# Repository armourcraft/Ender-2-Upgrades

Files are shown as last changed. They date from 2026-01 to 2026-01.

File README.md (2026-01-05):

# Ender 2 Base Upgrade

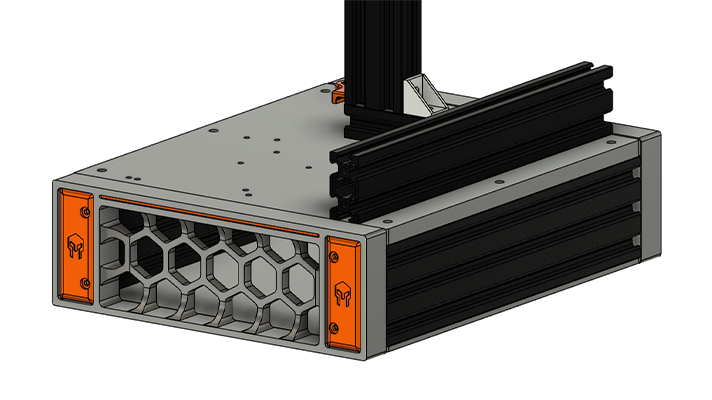
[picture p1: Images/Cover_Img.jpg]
Ender 2 Base Upgrade


This repository is for my upgrades to the original Ender 2. This upgrade can use the existing main board or the BigTreeTech SKR Mini E3 v3 running either Marlin or Klipper. 

## Features
- Footprint is slightly larger making it a little more stable.
- The power supply is under the printer and fully enclosed.
- The new base plate is designed for both old and new main boards.

## Build Tips
Print Settings are as follows:
- FDM Material: ABS recommended, but PETG will work too 
- Layer Height: 0.2mm
- Extrusion Width: 0.4mm
- Infill Percentage: 40% or more recommended
- Infill Type: Gyroid or Grid (others might work as well, experiment)
- Wall Count: 4
- Solid Top/Bottom Layers: 5
- Supports: All files designed to not require supports.

## BOM
### Fasteners:
| Fastener | Qty | Where Used |
| :--- | :---: | :--- |
| M3x6 BHCS  | 12 | grill covers, psu mounts, psu riser |
| M3x8 BHCS | 5 | grill fan, psu fan extension |
| M3x8 FHCS | 2 | power outlet |
| M3x10 BHCS | 3 | main board cover posts |
| M3x12 BHCS | 2 | main board fan mount |
| M3x14 BHCS | 2 | power cable guard |
| M3x16 BHCS | 4 | main board |
| M3 Hex Nuts | 4 | main board fan mount, power cable guard |
| M3 T-Nuts | 3 | power supply |
| M3x5x4 Threaded Inserts | 14 | grills, grill fan, power outlet |
| | | |
| M4x12 BHCS | 4 | bottom panel feet |
| M4 T-Nuts | 4 | bottom panel feet |
| | | |
| M5x10 SHCS | 2 | psu mounts |
| M5x14 BHCS | 6 | base plate extrusions |
| M5x16 SHCS | 12 | grills |
| M5 T-Nuts | 8 | base plate extrusions |

### Parts:
| Item | Qty | Description | Source |
| :---- | :---: | :--- | :--- |
| V-Slot 2060 Extrusion 250mm | 2 | need +1mm for clearance | [Amazon](https://www.amazon.com/dp/B0D1KCGV5D) - came 251mm |
| ABS Sheet 12"x12"x3/8" | 1 | route out new base plate | [Amazon](https://www.amazon.com/dp/B0CLY9Y116) |
| Cooling Fan Y Splitter | 1 | mod the psu for two fans | [Amazon](https://www.amazon.com/dp/B0D4MFT6H9) |
| LC6015MS14 Fan 6015 14V | 1 | second fan for back grill | [Amazon](https://www.amazon.com/dp/B0DFH5X8SG) |
| Power Outlet  | 1 | back grill outlet | [Amazon](https://www.amazon.com/dp/B07RRY5MYZ) |
| Rubber Feet 18x15x11mm | 4 | bottom panel | [Amazon](https://www.amazon.com/gp/product/B07LCM3SBW) |
| Spring Sheet Build Plate | 1 | better than original | [Amazon](https://www.amazon.com/dp/B0CJ92Z24N) |
| Metal Extruder | 1 | replace the plastic extruder | [Amazon](https://www.amazon.com/Creality-Official-Extruder-3D-Aluminum/dp/B09LQKN5WG) |
| Part Cooling Fan | 1 | will need to tap the hotend cover for M2 | [Amazon](https://www.amazon.com/dp/B0C2VSJTYQ) |
| Hotend Silicone Sock | 1 | optional: helps with keeping things clean | [Amazon](https://www.amazon.com/Printer-Hotend-Silicone-Heater-Creality/dp/B09VKZJKQ2) |

## License & Copyright
The above information is provided under GNU GPLv3. More information can be found in the License file.\
Copyright © 2021 Armour Craft LLC\

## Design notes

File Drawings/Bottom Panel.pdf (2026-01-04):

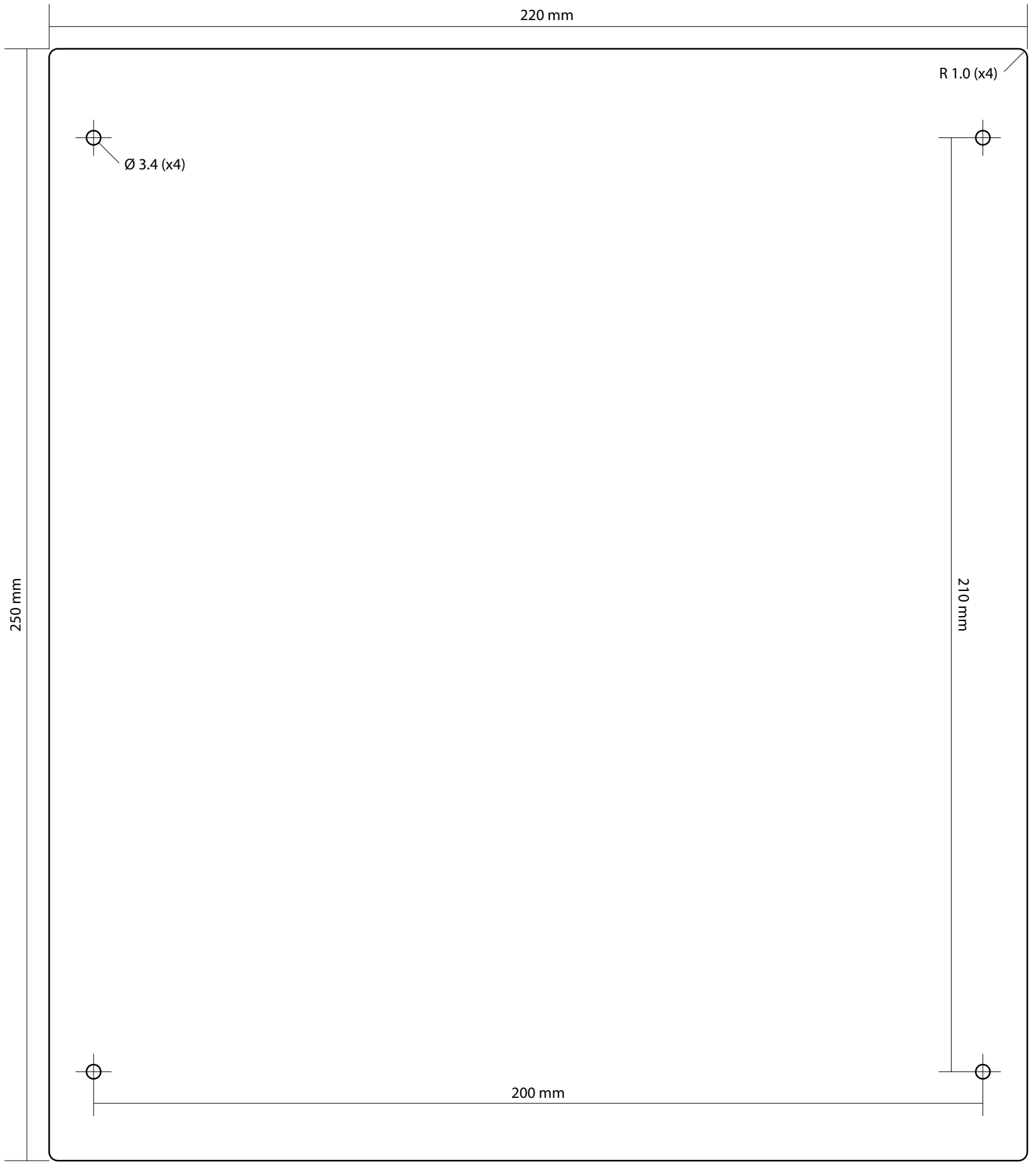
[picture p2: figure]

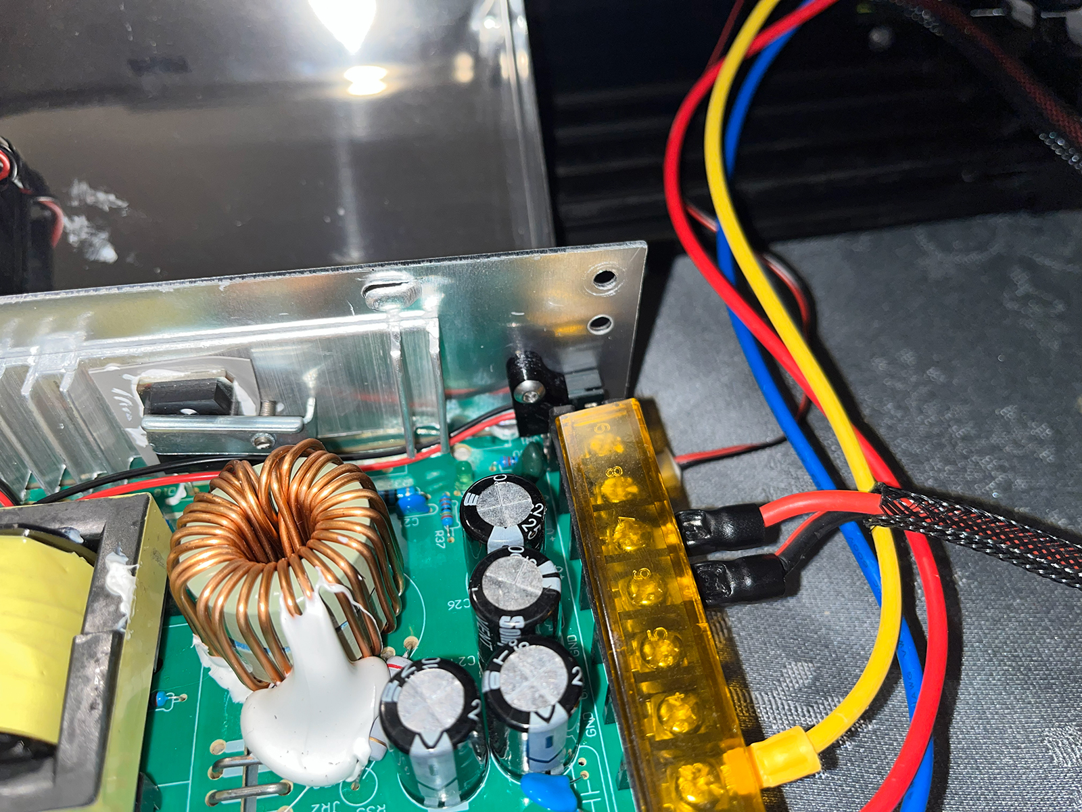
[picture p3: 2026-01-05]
Images/power supply mod - y splitter.jpg

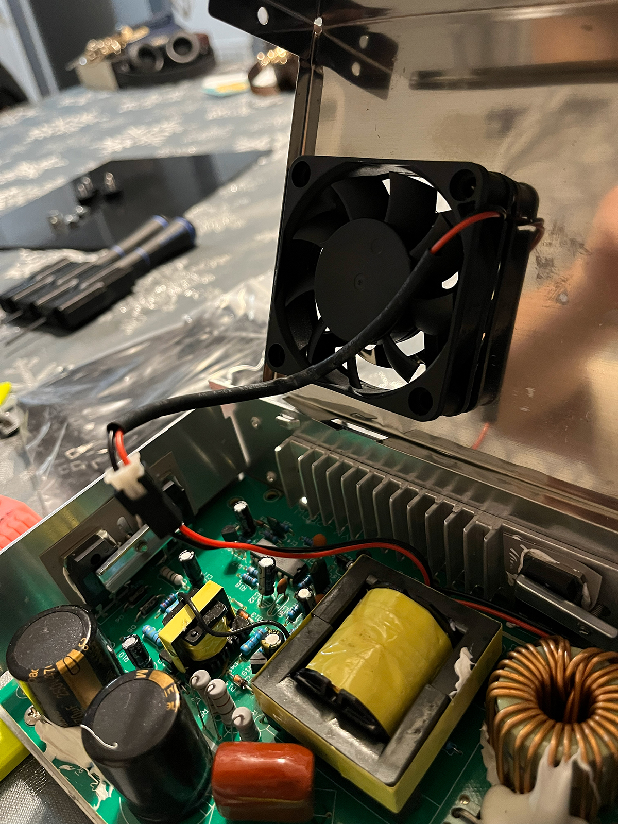
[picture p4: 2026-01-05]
Images/power supply mod - fan connection.jpg

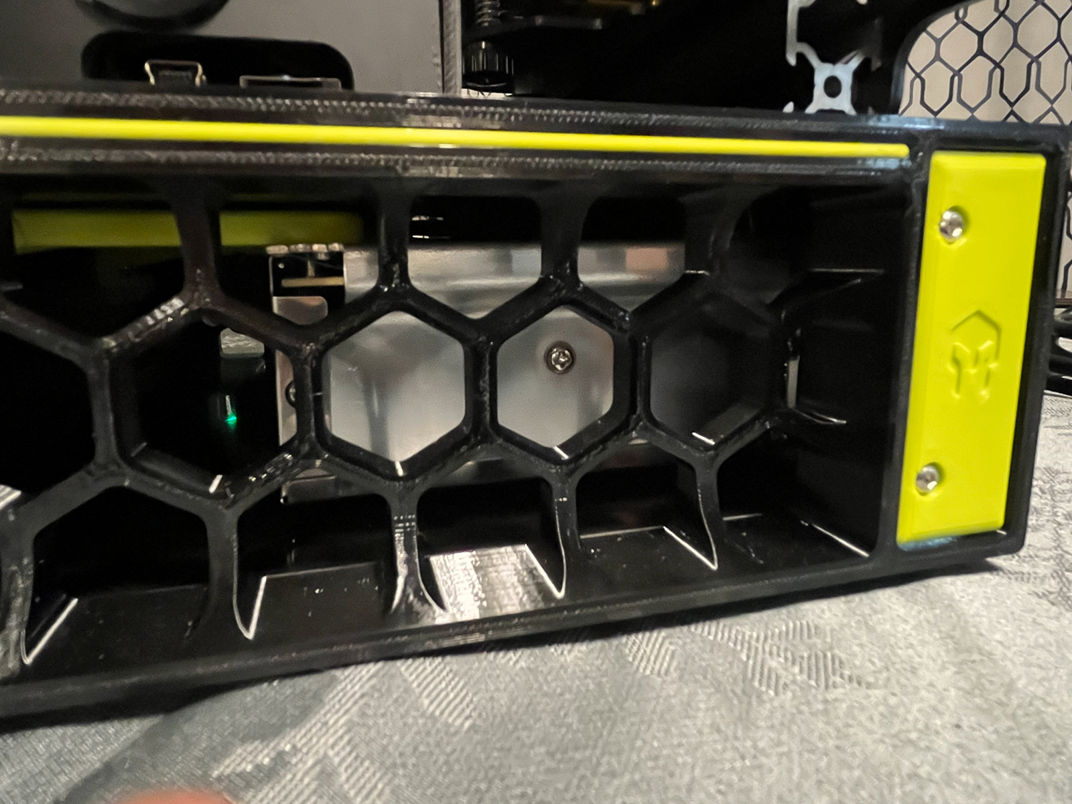
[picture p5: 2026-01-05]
Images/front grill.jpg

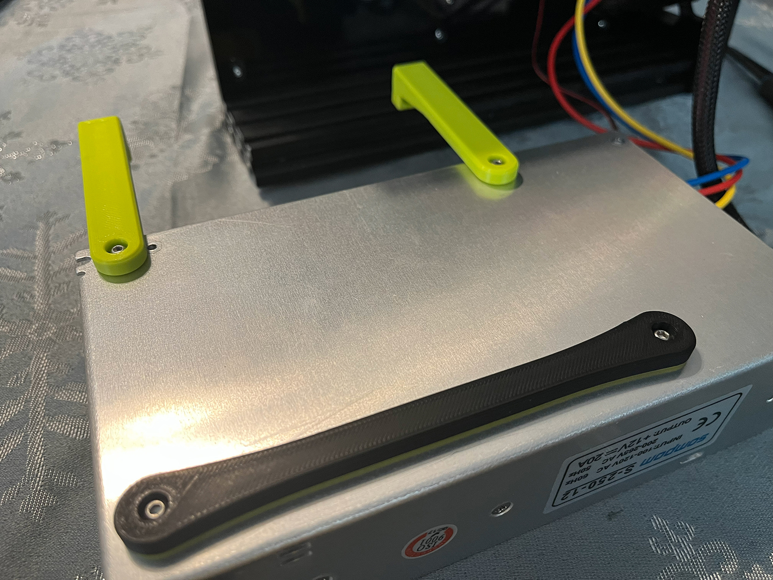
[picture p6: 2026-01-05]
Images/power supply riser and mounts.jpg

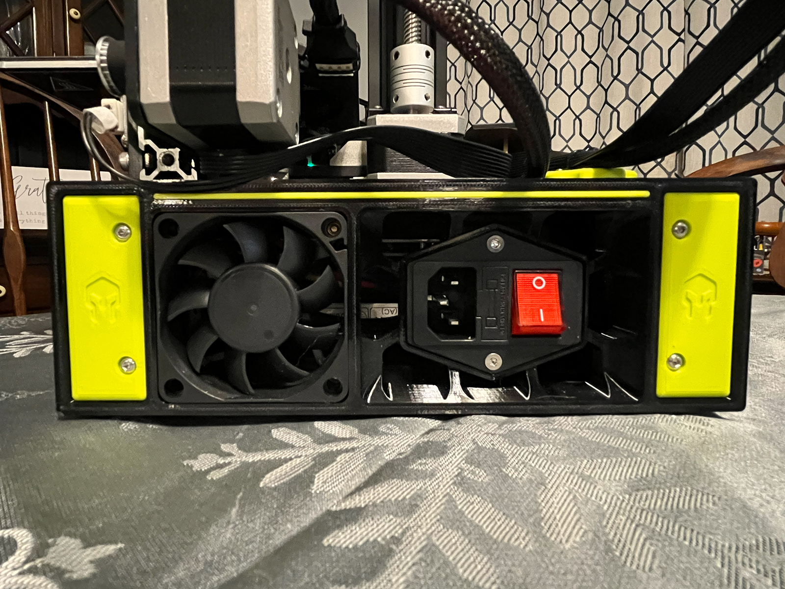
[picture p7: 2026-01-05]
Images/back grill.jpg

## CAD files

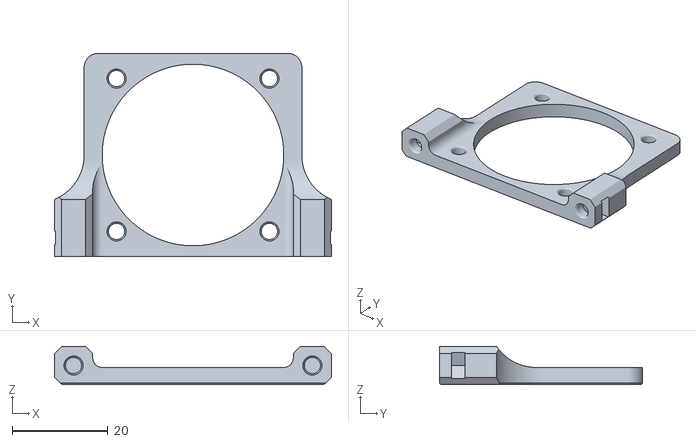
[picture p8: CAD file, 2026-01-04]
STLs/main_board_fan_mount.stl
58.0 x 42.6 x 8.00

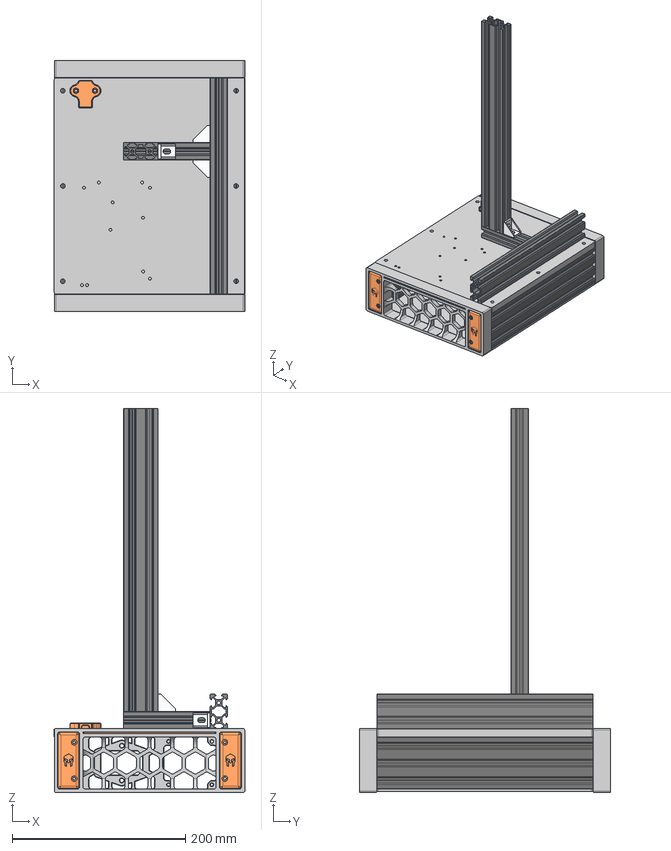
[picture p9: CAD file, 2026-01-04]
CAD/Ender 2 Base Enclosure.step
220.0 x 290.0 x 443.5 mm
V-Slot 20x60x500 Linear Rail x 2
Front Grill
Grill Cover Left x 2
Grill Cover Right x 2
Grill Inserts x 2
Base Plate
Back Grill
V-Slot 20x20x500 Linear Rail
V-Slot 20x40x500 Linear Rail
V-Slot 20x40x500 Linear Rail_1
Cast Corner Bracket x 3
Bottom Panel
Power Cable Restraint

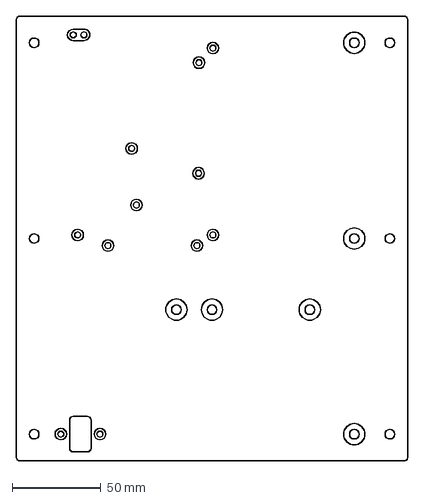
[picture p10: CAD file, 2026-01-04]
DXFs/Deck.dxf
220.0 x 250.0 mm

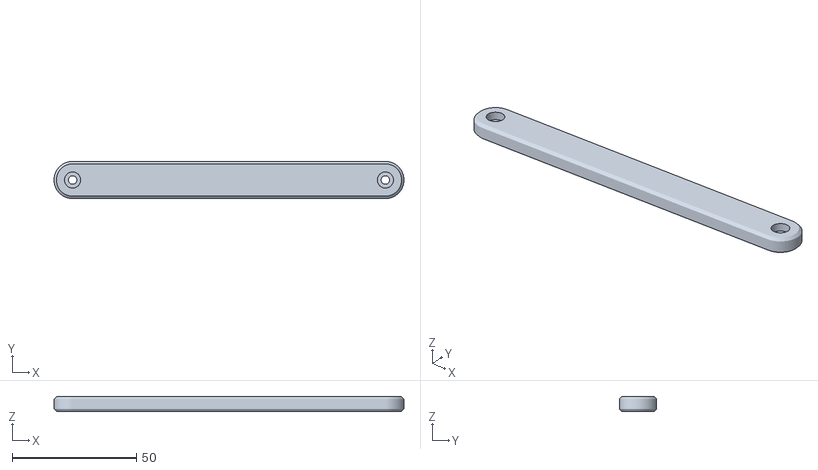
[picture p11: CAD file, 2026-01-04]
STLs/[a]_psu_riser.stl
141.0 x 15.0 x 6.00

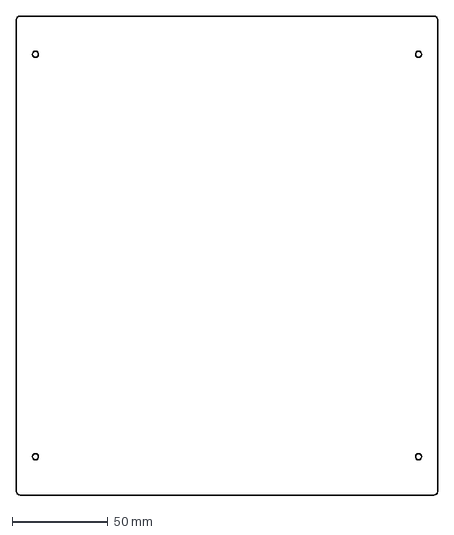
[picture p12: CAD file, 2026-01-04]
DXFs/Bottom Panel.dxf
220.0 x 250.0 mm

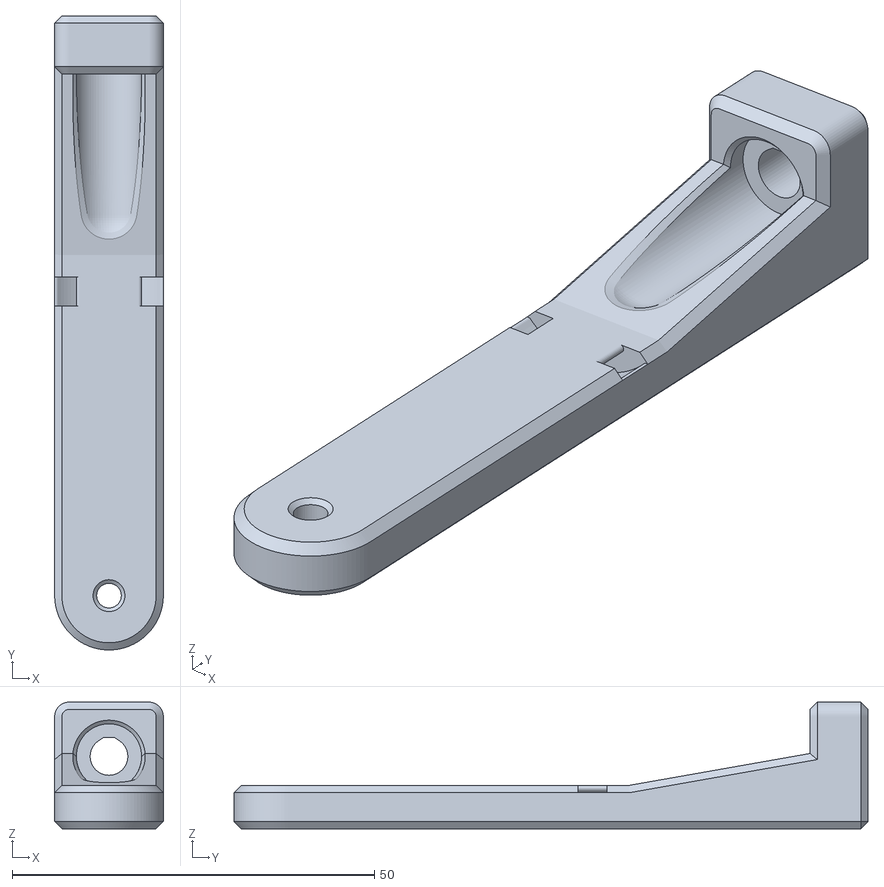
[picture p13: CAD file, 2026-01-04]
STLs/[a]_psu_mounts.stl
15.0 x 87.5 x 17.5

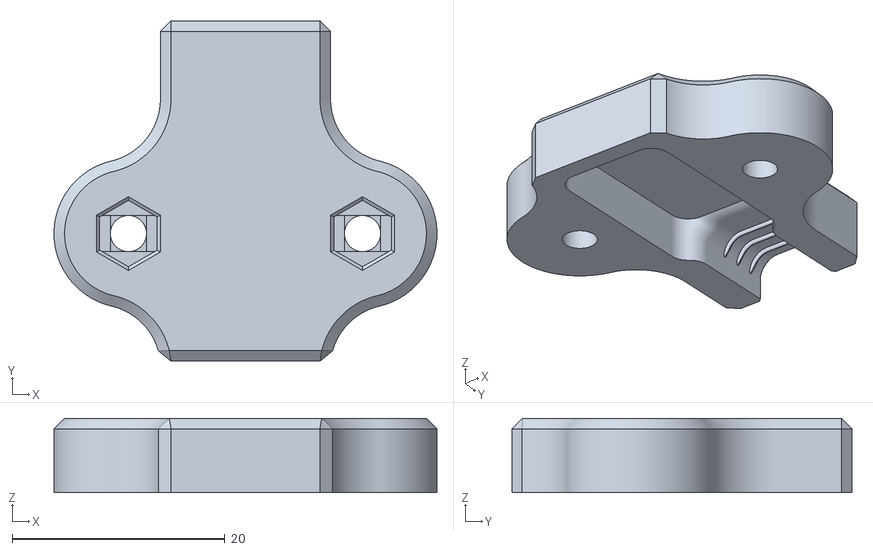
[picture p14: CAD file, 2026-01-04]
STLs/[a]_power_cable_guard.stl
36.0 x 32.0 x 7.00

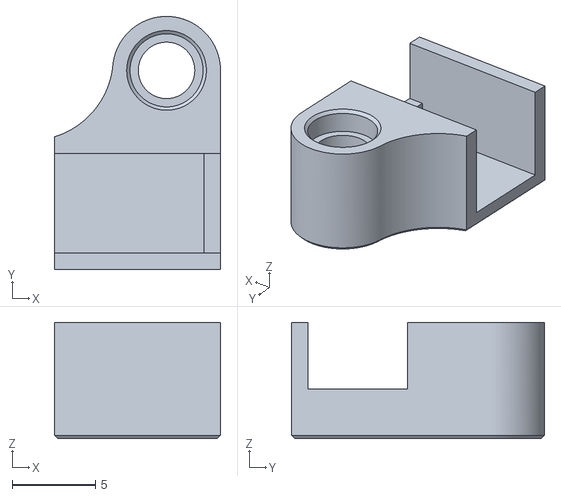
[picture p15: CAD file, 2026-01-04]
STLs/psu_fan_extension.stl
10.0 x 15.2 x 7.00

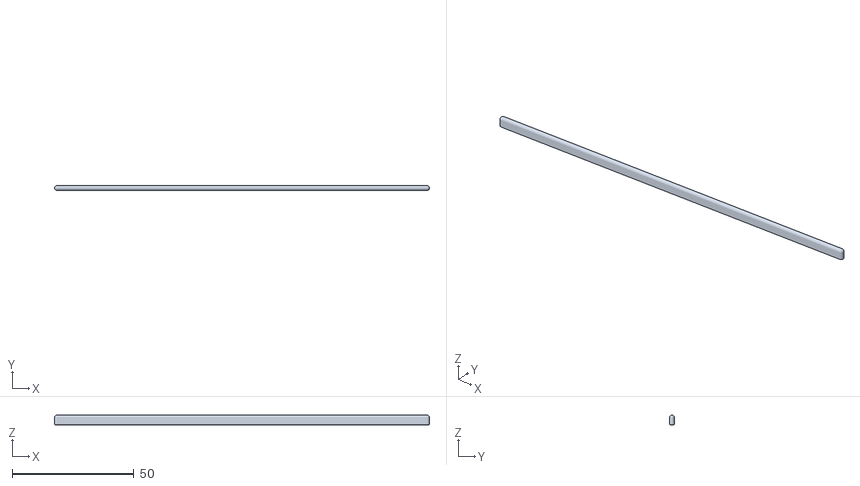
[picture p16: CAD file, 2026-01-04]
STLs/[a]_grill_inserts.stl
153.8 x 2.00 x 4.00

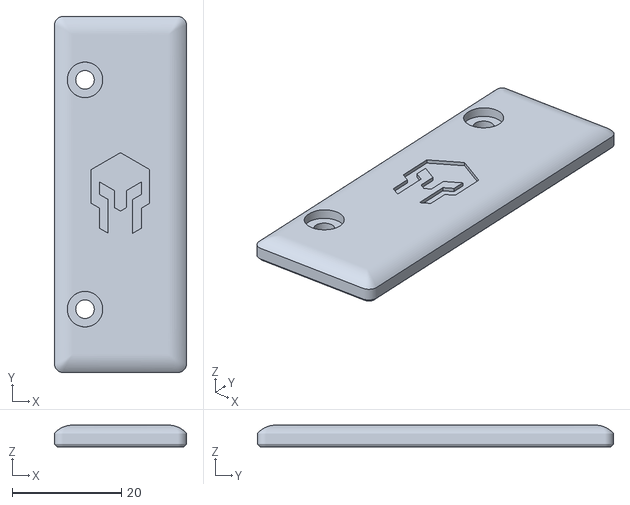
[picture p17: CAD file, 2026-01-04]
STLs/[a]_grill_cover_right.stl
24.2 x 65.2 x 4.00

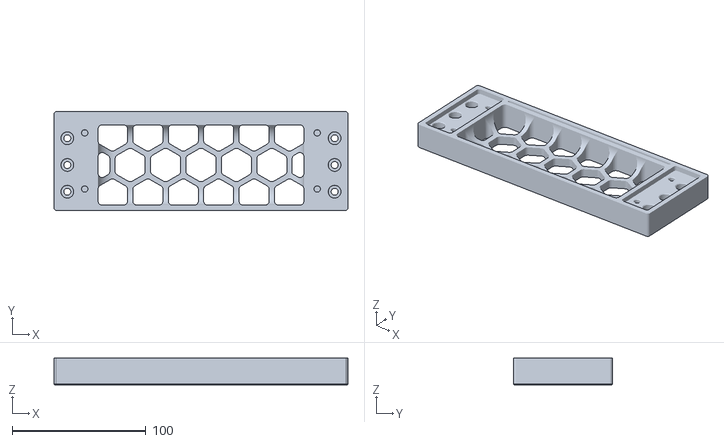
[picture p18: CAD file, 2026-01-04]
STLs/front_grill.stl
220.0 x 74.0 x 20.0

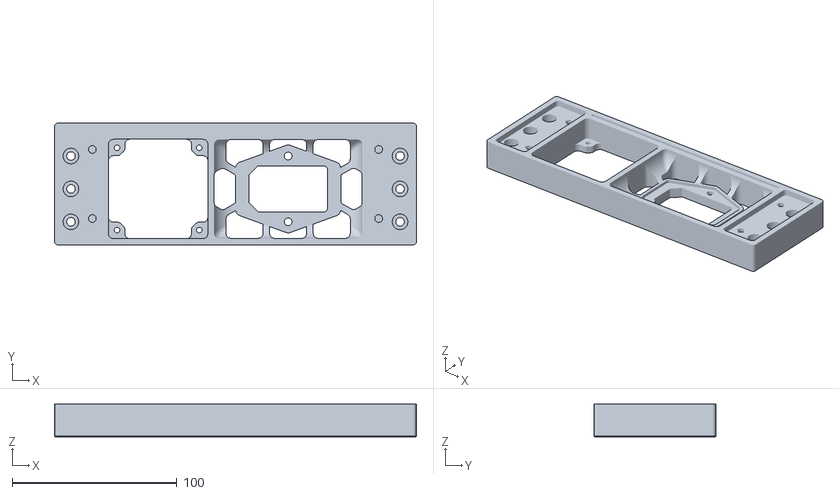
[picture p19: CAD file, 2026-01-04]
STLs/back_grill.stl
220.0 x 74.0 x 20.0

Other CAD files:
STLs/[a]_grill_cover_left.stl

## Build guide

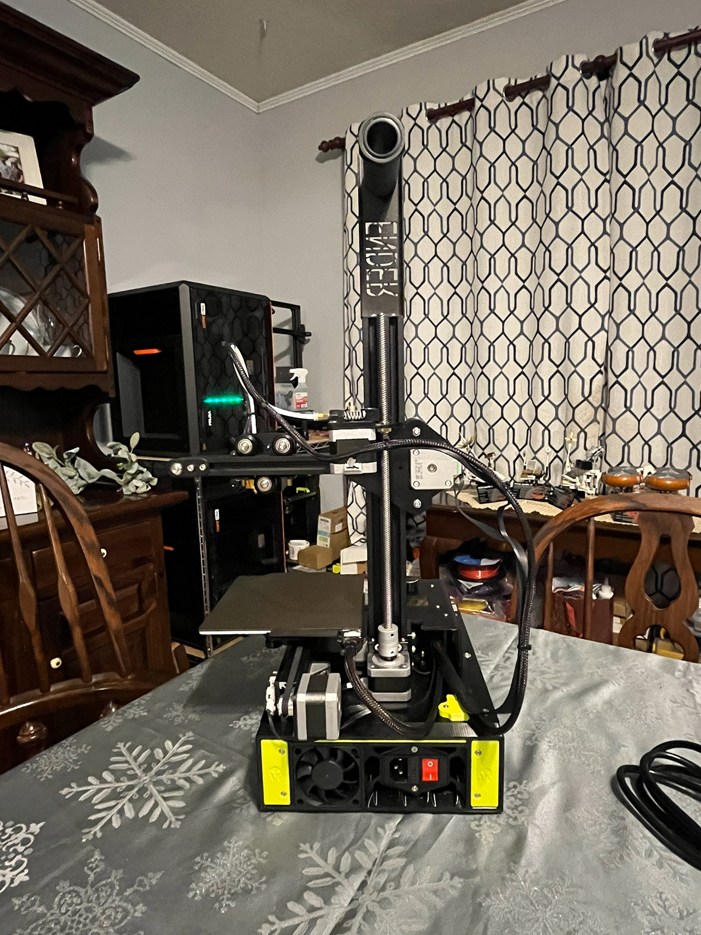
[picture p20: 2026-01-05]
Images/Assembly - back.jpg

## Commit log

2026-01-04 Create Ender 2 Base Enclosure.step
    [Ender 2 Base Enclosure.step]
2026-01-04 Create Bottom Panel.dxf
    [Bottom Panel.dxf]
2026-01-04 Create Back Grill.stl
    [Back Grill.stl]
2026-01-04 Create Electronics Fan Mount.stl
    [Electronics Fan Mount.stl]
2026-01-04 Create Front Grill.stl
    [Front Grill.stl]
2026-01-04 Create Grill Cover Left.stl
    [Grill Cover Left.stl]
2026-01-04 Create Grill Cover Right.stl
    [Grill Cover Right.stl]
2026-01-04 Create Grill Inserts.stl
    [Grill Inserts.stl]
2026-01-04 Create JST Connector Retainer.stl
    [JST Connector Retainer.stl]
2026-01-04 Create Power Cable Restraint.stl
    [Power Cable Restraint.stl]
2026-01-04 Create Power Supply Mount.stl
    [Power Supply Mount.stl]
2026-01-04 Create Power Supply Riser.stl
    [Power Supply Riser.stl]
2026-01-05 Create Assembly - back.jpg
2026-01-05 Create Assembly - front.jpg
2026-01-05 Create power supply mod - fan connection.jpg
2026-01-05 Create power supply mod - y splitter.jpg
2026-01-05 Create power supply riser and mounts.jpg
